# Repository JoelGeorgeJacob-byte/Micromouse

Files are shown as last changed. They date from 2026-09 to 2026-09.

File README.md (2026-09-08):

# Micromouse

An autonomous maze-solving robot designed to navigate a maze by detecting walls, controlling its motion, and executing turns with feedback from multiple sensors.

The robot combines distance sensing, wheel encoders, and an IMU to control its movement and improve its ability to travel straight and execute accurate turns.

## Demo

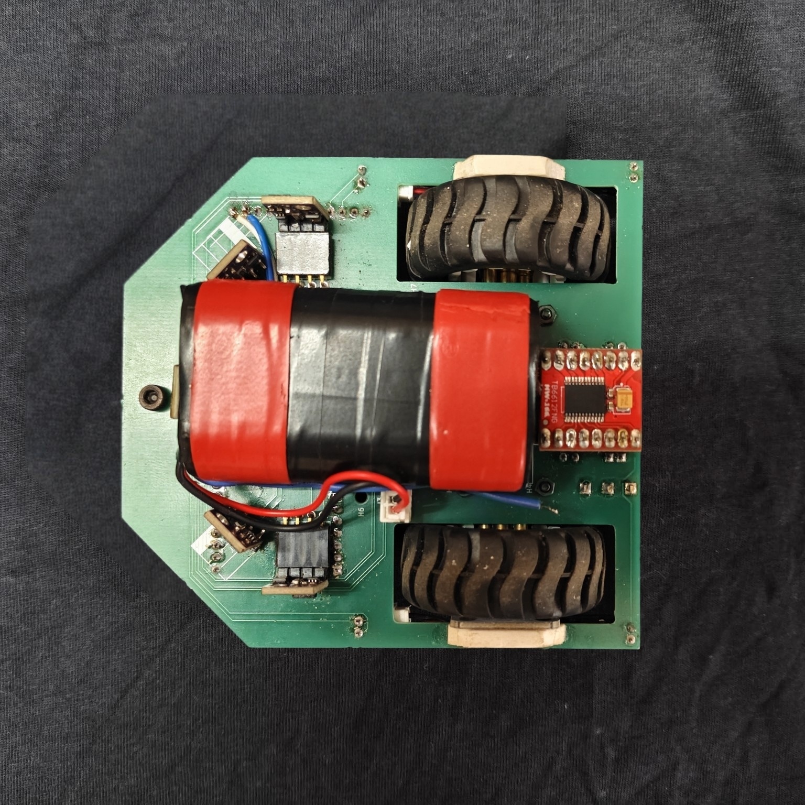
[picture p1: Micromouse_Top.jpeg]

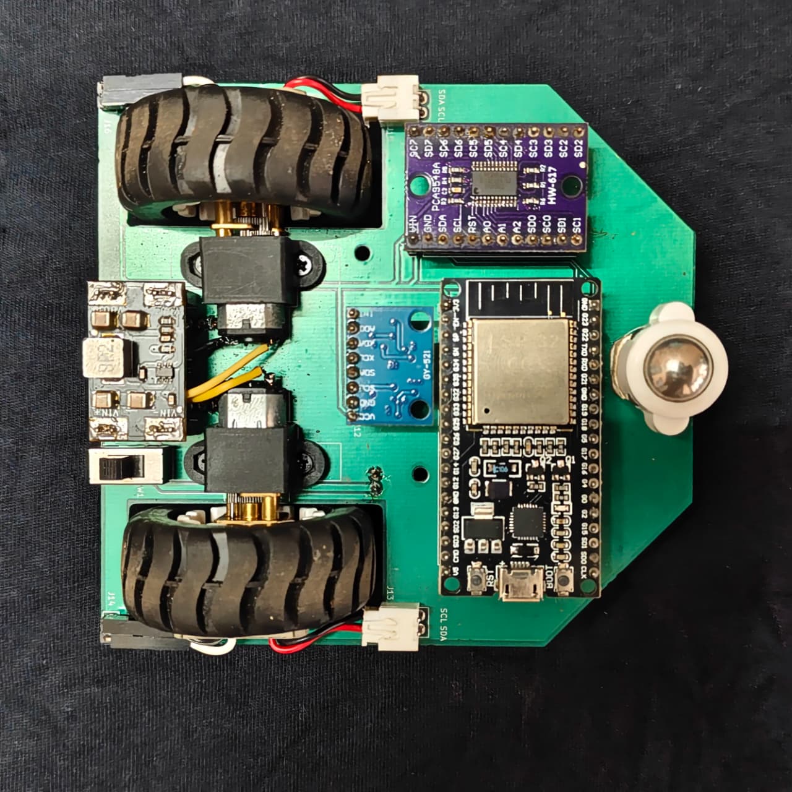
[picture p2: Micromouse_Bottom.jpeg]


## Hardware

* **MCU:** ESP32
* **Motor driver:** TB6612FNG
* **Distance sensing:** 5 × VL53L0X ToF sensors
* **Sensor multiplexer:** TCA9548A
* **Encoders:** 2 × AS5600 magnetic encoders
* **IMU:** MPU6050
* **Motors:** 2 × N20 geared motors
* **Wheels:** 40 mm
* **Power:** 7.4 V Li-ion battery
* **Communication:** I²C

## How It Works

The robot uses multiple VL53L0X ToF sensors to measure the distance to the surrounding walls. The sensors are connected through a TCA9548A I²C multiplexer to allow multiple identical sensors to operate on the same bus.

AS5600 magnetic encoders provide wheel movement feedback, allowing the ESP32 to measure the speed of each motor independently. A closed-loop motor speed controller adjusts the motor PWM to follow the required wheel speeds.

For wall following and centering, the difference between the left and right wall distances is used as the steering error. The controller adjusts the relative speed of the two motors to keep the robot aligned within the corridor.

An MPU6050 gyroscope provides yaw-rate feedback for additional motion stabilization and is also used during turns. Combining encoder feedback, ToF measurements, and gyro feedback allows the robot to control both its translational motion and heading.

The robot's navigation and turning behaviour were developed and tuned through repeated testing on the maze.

## Control System

The robot uses multiple feedback mechanisms:

* **Motor speed control:** Encoder-based closed-loop control
* **Wall centering:** Distance-based steering correction
* **Heading stabilization:** Gyroscope feedback
* **Turn control:** Gyro and encoder-assisted turning
* **Sensor calibration:** Individual sensor and gyro calibration
* **Motor calibration:** Compensation for differences between the two motors

## Challenges & Debugging

### 1. Uncommanded Drift (Hardware Degradation & PID Runaway)

**The Problem:** After a month of inactivity, degradation in the right motor caused the robot to drive straight for 1–2 feet before violently steering into the right wall — with no code changes made in between.

**The Solution:** Traced the fault to the degraded motor rather than the control logic. Replacing the motor and recalibrating resolved the issue, confirming the original PID tuning had been correct all along — the hardware, not the software, had drifted.

### 2. Motor Asymmetry & Open-Loop Calibration

**The Problem:** Out-of-the-box DC motors are never perfectly matched, and after replacing the right motor, the existing PID constants no longer fit the new hardware pairing.

**The Solution:** Wrote a dedicated open-loop calibration script to bypass all navigation logic entirely. By feeding manual PWM values and measuring the response, I calculated exact stiction offsets (`PWM_OFFSET_L/R`) and linear feedforward slopes (`FF_SLOPE_L/R`) for the new motors. This gave the PID controller a mathematically accurate baseline, letting the bot track straight before sensor feedback even engaged.

### 3. Zigzag Blind Spots (Corner Clipping)

**The Problem:** The robot navigated straight corridors cleanly but clipped inner corner pegs during zigzag maneuvers. The original Left/Right/Center ToF layout only looked straight ahead and directly sideways — the 45° front corners of the robot were completely blind.

**The Solution:** Added two diagonal VL53L0X sensors to cover the blind corners. Upgraded the TCA9548A multiplexer's round-robin polling from a 3-state to a 5-state non-blocking switch, so all five sensors could be read continuously without blocking the 100Hz motor control loop.

### 4. Sensor Deadzone Blindness (<40mm Hardware Limit)

**The Problem:** VL53L0X sensors lose accuracy below ~40mm and eventually return a timeout code (8190). Since the steering logic was proportional (`Target − Current Distance`), the correction flatlined or disabled itself right when the robot was inches from a crash.

**The Solution:** Implemented a software "deadzone latch": if a sensor reported a danger-range reading and then suddenly jumped to the 8190 timeout, the system assumed a wall/peg had breached the deadzone and forced the motors into a fixed, aggressive "bang-bang" evasive maneuver instead of trusting the (now-meaningless) proportional value.

### 5. Inertia vs. False Positives (Tuning Hysteresis)

**The Problem:** Setting the evasive trigger distance too short failed outright — at high speeds, the robot's momentum meant it crashed before the wheels could spin down in time. Raising the threshold to a safer distance avoided corner crashes but caused violent swerving on straightaways, since a flat side wall is detected much closer by an angled sensor. Compounding this, raising the danger trigger without properly adjusting the clear trigger broke the hysteresis logic entirely.

**The Solution:** Found the geometric sweet spot just under the straight-wall distance while maintaining a proper hysteresis gap. To compensate for the later trigger point, I added an instant active brake the moment an evasive maneuver starts, giving the tires the grip and time needed to execute a tight pivot instead of skidding into the corner.

### 6. Linear vs. Exponential Correction

**The Problem:** The initial proportional/linear correction produced insufficient response for large positional errors while becoming unnecessarily sensitive around smaller errors. This was particularly noticeable when using the diagonal sensors near angled walls.

**The Solution:** The correction was changed to an exponential response, allowing small deviations to produce gentle corrections while increasing the response more aggressively as the error became larger.

## Results

* **Development Testing:** Successfully and consistently navigated a custom-built test maze during the prototyping phase.
* **Competition Debut:** Competed in Mazerunner Competition conducted by GEC Thrissur, successfully clearing 3 out of 8 corridors on its first official run. 
* **Ongoing Iteration:** The competition highlighted critical edge-cases (such as the zigzag corner-clipping), which directly drove the V2 hardware and software upgrades documented in the challenges above.

The robot was successfully developed from individual hardware components into an autonomous maze-solving platform.

The project involved the development and integration of:

* Sensor-based wall detection
* Encoder-based motor feedback
* Closed-loop motor speed control
* Gyroscope-based heading feedback
* Autonomous turning
* Sensor and motor calibration

The robot was tested and tuned through multiple iterations, with each stage used to identify and correct mechanical, electrical, sensing, and control-related issues.

### Basic Setup

1. Assemble the chassis, motors, sensors, encoders, and motor driver.
2. Connect the VL53L0X sensors and AS5600 encoders through the TCA9548A multiplexer.
3. Connect the MPU6050 to the ESP32.
4. Connect the TB6612FNG to the ESP32 and motors.
5. Upload the firmware to the ESP32.
6. Perform the required sensor and motor calibration.
7. Test straight-line movement and turning before running the robot in the maze.

## Project Structure

* `Micromouse_Code.ino` - Main C++ firmware for the ESP32 (motor control, PID, and navigation).
* `README.md` - Documentation and project overview.
* `Micromouse_Top.jpeg` - Photo of the top view.
* `Micromouse_Bottom.jpeg` - Photo of the bottom view.
* `Micromouse_Gerber.zip` - Raw PCB Gerber file.

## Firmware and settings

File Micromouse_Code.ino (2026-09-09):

#include <Wire.h>
#include <VL53L0X.h>

// ============================================================================
// HARDWARE PIN MAPPING (ESP32 Core 3.x)
// ============================================================================
#define PIN_STBY     19
#define PIN_PWMA     25
#define PIN_AIN1     26
#define PIN_AIN2     27
#define PIN_PWMB     32
#define PIN_BIN1     33
#define PIN_BIN2     23

#define PIN_SDA_MAIN 21
#define PIN_SCL_MAIN 22
#define TCA_ADDR     0x70
#define AS5600_ADDR  0x36

#define PIN_SDA_GYRO 16
#define PIN_SCL_GYRO 17
#define MPU_ADDR     0x68

#define CH_TOF_LEFT   0
#define CH_TOF_DIAG_L 1
#define CH_TOF_CENTER 2
#define CH_TOF_DIAG_R 3
#define CH_TOF_RIGHT  4
#define CH_ENC_LEFT   5
#define CH_ENC_RIGHT  6

// ============================================================================
// CONFIGURATION & TUNING
// ============================================================================
const int SAFE_DIST_MIN     = 45;  
const int SAFE_DIST_MAX     = 80;  
const int FRONT_TURN_DIST   = 100;  

const float BASE_RPM        = 200.0; 
const float MAX_STEER_RPM   = 50.0;  

const float DECEL_ZONE_START_MM = 300.0f; 
const float APPROACH_RPM        = 55.0f;  

const float SAFE_DIST_MID   = (SAFE_DIST_MIN + SAFE_DIST_MAX) / 2.0f;
const float KP_CENTER       = 0.5f;   
const float KD_CENTER       = 0.2f;  

const float KGYRO = 0.30f; 

const int WALL_APPEAR_DIST    = 150;
const int WALL_DISAPPEAR_DIST = 180;

const int   DIAG_DANGER_DIST     = 100;    
const int   DIAG_FLOOR_MM        = 25;   
const int   DIAG_CLEAR_DIST      = 110;   
const int   DIAG_TRIP_DEBOUNCE   = 2;    
const float DIAG_CORRECT_KP      = 3.0f;  
const float DIAG_CORRECT_RPM_MIN = 25.0f; 
const float DIAG_CORRECT_RPM_MAX = 90.0f; 

const float RAMP_STAGE_DIST_MM = 60.0f;                      
const float RAMP_STAGE_RPM[3]  = {60.0f, 80.0f, 100.0f};     
const int   RAMP_STAGE_COUNT   = 3;                          

const float KP_MOTOR = 0.35;
const float KI_MOTOR = 0.80;
const float FF_SLOPE_L = 168.0 / 324.0;
const float FF_SLOPE_R = 149.0 / 302.0;

const int PWM_OFFSET_L = 85;
const int PWM_OFFSET_R = 90;
const float MAX_INTEGRAL_PWM = 40.0;

const int OFFSET_LEFT   = 12;
const int OFFSET_CENTER = 15;
const int OFFSET_RIGHT  = 11;
const int OFFSET_DIAG_L = 16;  
const int OFFSET_DIAG_R = 16;  

const float WHEEL_DIAMETER_MM = 40.0f;
const float MM_PER_COUNT = (PI * WHEEL_DIAMETER_MM) / 4096.0f;

const float GYRO_SENS_LSB_PER_DPS  = 131.0f;  
const float TURN_TARGET_DEG        = 82.0f;
const float HEADING_TOLERANCE_DEG  = 2.0f;    
const float GYRO_RATE_THRESHOLD_DPS= 8.0f;    
const float KP_TURN                = 1.2f;    
const float MIN_PIVOT_RPM          = 45.0f;   
const float MAX_PIVOT_RPM          = 90.0f;
const unsigned long TURN_TIMEOUT_MS = 3000;   

// ============================================================================
// GLOBAL STATE VARIABLES
// ============================================================================
VL53L0X tofLeft, tofCenter, tofRight;
VL53L0X tofDiagL, tofDiagR; 

unsigned long prevMotorTime = 0;
uint8_t tofSequenceState    = 0; 

int16_t prevTickL = -1, prevTickR = -1;
float actualRpmL = 0.0, actualRpmR = 0.0;

float integralL = 0.0, integralR = 0.0;
float smoothSteerRPM = 0.0; 
float smoothForwardRpm = BASE_RPM; 

float targetRpmL = BASE_RPM;
float targetRpmR = BASE_RPM;

int dLeft = 8190, dCenter = 8190, dRight = 8190;
int dDiagL = 8190, dDiagR = 8190; 

bool leftWallPresent  = false;
bool rightWallPresent = false;
bool diagLDanger = false; 
bool diagRDanger = false; 
int diagLTripCount = 0, diagRTripCount = 0; 
unsigned long lastSteerMs = 0;
float prevSteerError = 0.0f;

float distanceSinceTurnMm  = 0.0f;
bool  postTurnRampActive   = false;

float gyroZBiasRaw = 0.0f; 

// ============================================================================
// I2C & HARDWARE UTILITIES
// ============================================================================
void selectMux(uint8_t channel) {
  Wire.beginTransmission(TCA_ADDR);
  Wire.write(1 << channel);
  Wire.endTransmission();
}

int16_t readEncoder(uint8_t channel) {
  selectMux(channel);
  Wire.beginTransmission(AS5600_ADDR);
  Wire.write(0x0C);
  if (Wire.endTransmission(false) != 0) return -1;
  Wire.requestFrom((int)AS5600_ADDR, 2);
  if (Wire.available() < 2) return -1;
  return ((Wire.read() << 8) | Wire.read()) & 0x0FFF;
}

bool tofDataReady(VL53L0X &sensor) {
  return (sensor.readReg(0x13) & 0x07) != 0;
}

// ============================================================================
// GYRO (MPU6050 on Wire1)
// ============================================================================
void mpuWriteReg(uint8_t reg, uint8_t val) {
  Wire1.beginTransmission(MPU_ADDR);
  Wire1.write(reg);
  Wire1.write(val);
  Wire1.endTransmission();
}

int16_t mpuReadGyroZRaw() {
  Wire1.beginTransmission(MPU_ADDR);
  Wire1.write(0x47); 
  if (Wire1.endTransmission(false) != 0) return 0;
  Wire1.requestFrom((int)MPU_ADDR, 2);
  if (Wire1.available() < 2) return 0;
  uint8_t hi = Wire1.read();
  uint8_t lo = Wire1.read();
  return (int16_t)((hi << 8) | lo);
}

void initGyro() {
  Wire1.begin(PIN_SDA_GYRO, PIN_SCL_GYRO);
  Wire1.setClock(400000);

  mpuWriteReg(0x6B, 0x00); 
  delay(50);
  mpuWriteReg(0x1B, 0x00); 

  const int N = 400;
  long sum = 0;
  for (int i = 0; i < N; i++) {
    sum += mpuReadGyroZRaw();
    delay(2);
  }
  gyroZBiasRaw = sum / (float)N;
}

float readGyroZDps() {
  int16_t raw = mpuReadGyroZRaw();
  return (raw - gyroZBiasRaw) / GYRO_SENS_LSB_PER_DPS;
}

// ============================================================================
// LAYER 1: MOTOR SPEED CONTROLLER
// ============================================================================
void initMotors() {
  pinMode(PIN_STBY, OUTPUT);
  pinMode(PIN_AIN1, OUTPUT); pinMode(PIN_AIN2, OUTPUT);
  pinMode(PIN_BIN1, OUTPUT); pinMode(PIN_BIN2, OUTPUT);
  digitalWrite(PIN_STBY, HIGH); 
  
  ledcAttach(PIN_PWMA, 20000, 8);
  ledcAttach(PIN_PWMB, 20000, 8);
}

void applyMotorPWM(int leftPWM, int rightPWM) {
  leftPWM = constrain(leftPWM, -255, 255);
  rightPWM = constrain(rightPWM, -255, 255);

  if (leftPWM >= 0) { digitalWrite(PIN_AIN1, LOW); digitalWrite(PIN_AIN2, HIGH); } 
  else              { digitalWrite(PIN_AIN1, HIGH); digitalWrite(PIN_AIN2, LOW); }
  ledcWrite(PIN_PWMA, abs(leftPWM));

  if (rightPWM >= 0) { digitalWrite(PIN_BIN1, LOW); digitalWrite(PIN_BIN2, HIGH); } 
  else               { digitalWrite(PIN_BIN1, HIGH); digitalWrite(PIN_BIN2, LOW); }
  ledcWrite(PIN_PWMB, abs(rightPWM));
}

void updateEncoders(float dt) {
  int16_t tickL = readEncoder(CH_ENC_LEFT);
  int16_t tickR = readEncoder(CH_ENC_RIGHT);

  float distL = 0.0f, distR = 0.0f;
  bool gotL = false, gotR = false;
  
  if (tickL >= 0 && prevTickL >= 0) {
    int16_t delta = tickL - prevTickL;
    if (delta > 2048) delta -= 4096;
    if (delta < -2048) delta += 4096;
    
    float rawRpmL = (1.0 * delta / 4096.0) * (60.0 / dt);
    actualRpmL = (0.3 * rawRpmL) + (0.7 * actualRpmL); 

    distL = (1.0f * delta) * MM_PER_COUNT; 
    gotL = true;
  }
  
  if (tickR >= 0 && prevTickR >= 0) {
    int16_t delta = tickR - prevTickR;
    if (delta > 2048) delta -= 4096;
    if (delta < -2048) delta += 4096;
    
    float rawRpmR = (-1.0 * delta / 4096.0) * (60.0 / dt);
    actualRpmR = (0.3 * rawRpmR) + (0.7 * actualRpmR); 

    distR = (-1.0f * delta) * MM_PER_COUNT;
    gotR = true;
  }
  
  if (tickL >= 0) prevTickL = tickL;
  if (tickR >= 0) prevTickR = tickR;

  if (postTurnRampActive && gotL && gotR) {
    distanceSinceTurnMm += (distL + distR) / 2.0f;
  }
}

void driveWheelsRPM(float targetL, float targetR, float dt) {
  targetL = constrain(targetL, -220.0, 220.0);
  targetR = constrain(targetR, -220.0, 220.0);

  float errorL = targetL - actualRpmL;
  integralL += errorL * dt;
  integralL = constrain(integralL, -MAX_INTEGRAL_PWM / KI_MOTOR, MAX_INTEGRAL_PWM / KI_MOTOR);

  float ffL = 0;
  if (targetL > 1)       ffL = PWM_OFFSET_L + targetL * FF_SLOPE_L;
  else if (targetL < -1) ffL = -(PWM_OFFSET_L + (-targetL) * FF_SLOPE_L);

  float pwmL = ffL + (KP_MOTOR * errorL) + (KI_MOTOR * integralL);
  pwmL = constrain(pwmL, -255, 255);

  float errorR = targetR - actualRpmR;
  integralR += errorR * dt;
  integralR = constrain(integralR, -MAX_INTEGRAL_PWM / KI_MOTOR, MAX_INTEGRAL_PWM / KI_MOTOR);

  float ffR = 0;
  if (targetR > 1)       ffR = PWM_OFFSET_R + targetR * FF_SLOPE_R;
  else if (targetR < -1) ffR = -(PWM_OFFSET_R + (-targetR) * FF_SLOPE_R);

  float pwmR = ffR + (KP_MOTOR * errorR) + (KI_MOTOR * integralR);
  pwmR = constrain(pwmR, -255, 255);

  applyMotorPWM((int)pwmL, (int)pwmR);
}

// ============================================================================
// LAYER 2 & 3: NAVIGATION & CORNERING
// ============================================================================

float computeRampedForwardRpm() {
  if (!postTurnRampActive) return BASE_RPM;

  int stage = (int)(distanceSinceTurnMm / RAMP_STAGE_DIST_MM);
  if (stage >= RAMP_STAGE_COUNT) {
    postTurnRampActive = false; 
    return BASE_RPM;
  }
  return RAMP_STAGE_RPM[stage];
}

float computeForwardRpm() {
  float target;
  if (dCenter <= 0 || dCenter >= DECEL_ZONE_START_MM) {
    target = BASE_RPM;
  } else if (dCenter <= FRONT_TURN_DIST) {
    target = APPROACH_RPM;
  } else {
    float t = (float)(dCenter - FRONT_TURN_DIST) / (float)(DECEL_ZONE_START_MM - FRONT_TURN_DIST);
    target = APPROACH_RPM + t * (BASE_RPM - APPROACH_RPM);
  }

  float rampTarget = computeRampedForwardRpm();
  if (rampTarget < target) target = rampTarget;

  smoothForwardRpm = 0.3f * target + 0.7f * smoothForwardRpm;
  return smoothForwardRpm;
}

void computeSteering() {
  if (dLeft > 0) {
    if (!leftWallPresent && dLeft < WALL_APPEAR_DIST)       leftWallPresent = true;
    else if (leftWallPresent && dLeft > WALL_DISAPPEAR_DIST) leftWallPresent = false;
  } else {
    leftWallPresent = false;
  }

  if (dRight > 0) {
    if (!rightWallPresent && dRight < WALL_APPEAR_DIST)        rightWallPresent = true;
    else if (rightWallPresent && dRight > WALL_DISAPPEAR_DIST) rightWallPresent = false;
  } else {
    rightWallPresent = false;
  }

  float effLeft  = leftWallPresent  ? (float)dLeft  : SAFE_DIST_MID;
  float effRight = rightWallPresent ? (float)dRight : SAFE_DIST_MID;
  float error = effRight - effLeft;

  unsigned long nowMs = millis();
  float dt = (lastSteerMs == 0) ? 0.02f : (nowMs - lastSteerMs) / 1000.0f;
  if (dt <= 0.0f) dt = 0.001f;
  lastSteerMs = nowMs;

  float derivative = (error - prevSteerError) / dt;
  prevSteerError = error;

  float yawRateDps = readGyroZDps();

  float rawSteerRPM = KP_CENTER * error + KD_CENTER * derivative - KGYRO * yawRateDps;
  rawSteerRPM = constrain(rawSteerRPM, -MAX_STEER_RPM, MAX_STEER_RPM);

  smoothSteerRPM = (0.3 * rawSteerRPM) + (0.7 * smoothSteerRPM);

  float baseRpm = computeForwardRpm();
  targetRpmL = baseRpm + smoothSteerRPM;
  targetRpmR = baseRpm - smoothSteerRPM;

  if (dDiagL > 0 && dDiagL < DIAG_DANGER_DIST) {
    diagLTripCount++;
    if (!diagLDanger && diagLTripCount >= DIAG_TRIP_DEBOUNCE) diagLDanger = true;
  } else {
    diagLTripCount = 0;
    if (diagLDanger && (dDiagL <= 0 || dDiagL > DIAG_CLEAR_DIST)) diagLDanger = false;
  }

  if (dDiagR > 0 && dDiagR < DIAG_DANGER_DIST) {
    diagRTripCount++;
    if (!diagRDanger && diagRTripCount >= DIAG_TRIP_DEBOUNCE) diagRDanger = true;
  } else {
    diagRTripCount = 0;
    if (diagRDanger && (dDiagR <= 0 || dDiagR > DIAG_CLEAR_DIST)) diagRDanger = false;
  }

  if (diagLDanger) {
    float correctRpm;
    if (dDiagL <= DIAG_FLOOR_MM) {
      correctRpm = DIAG_CORRECT_RPM_MAX; 
    } else {
      float penetration = (float)DIAG_DANGER_DIST - (float)dDiagL;
      float linear_rpm = DIAG_CORRECT_RPM_MIN + DIAG_CORRECT_KP * penetration;
      
      float safe_dist = max((float)dDiagL, 1.0f); 
      float proximity_ratio = (float)DIAG_DANGER_DIST / safe_dist;
      float multiplier = proximity_ratio * proximity_ratio;
      
      correctRpm = linear_rpm * multiplier;
      correctRpm = constrain(correctRpm, DIAG_CORRECT_RPM_MIN, DIAG_CORRECT_RPM_MAX);
    }
    targetRpmL = baseRpm + correctRpm; 
    targetRpmR = baseRpm - correctRpm; 
    
  } else if (diagRDanger) {
    float correctRpm;
    if (dDiagR <= DIAG_FLOOR_MM) {
      correctRpm = DIAG_CORRECT_RPM_MAX;
    } else {
      float penetration = (float)DIAG_DANGER_DIST - (float)dDiagR;
      float linear_rpm = DIAG_CORRECT_RPM_MIN + DIAG_CORRECT_KP * penetration;
      
      float safe_dist = max((float)dDiagR, 1.0f);
      float proximity_ratio = (float)DIAG_DANGER_DIST / safe_dist;
      float multiplier = proximity_ratio * proximity_ratio;
      
      correctRpm = linear_rpm * multiplier;
      correctRpm = constrain(correctRpm, DIAG_CORRECT_RPM_MIN, DIAG_CORRECT_RPM_MAX);
    }
    targetRpmL = baseRpm - correctRpm; 
    targetRpmR = baseRpm + correctRpm; 
  }
}

void executePivotTurn() {
  digitalWrite(PIN_AIN1, HIGH); digitalWrite(PIN_AIN2, HIGH);
  digitalWrite(PIN_BIN1, HIGH); digitalWrite(PIN_BIN2, HIGH);
  ledcWrite(PIN_PWMA, 255); ledcWrite(PIN_PWMB, 255);
  delay(60);
  applyMotorPWM(0, 0);
  delay(100); 

  integralL = 0;
  integralR = 0;
  smoothSteerRPM = 0;

  bool turnLeft = (dLeft > dRight);
  float currentHeadingDeg = 0.0f;
  float targetHeadingDeg = 999.0f; 
  bool centerCleared = false;

  float scanRpm = 45.0f; 

  unsigned long turnStartMs  = millis();
  unsigned long lastMotorMs  = millis();
  unsigned long lastGyroUs   = micros();

  while (true) {
    unsigned long nowMs = millis();
    unsigned long nowUs = micros();

    float gz = readGyroZDps();
    float gdt = (nowUs - lastGyroUs) / 1e6f;
    if (gdt > 0.0f) {
      currentHeadingDeg += gz * gdt;
      lastGyroUs = nowUs;
    }

    selectMux(CH_TOF_CENTER);
    if (tofDataReady(tofCenter)) {
      int raw = tofCenter.readRangeContinuousMillimeters();
      dCenter = (tofCenter.timeoutOccurred() || raw > 8000) ? 8190 : raw - OFFSET_CENTER;
    }

    float pivotRpm = 0.0f;

    if (!centerCleared) {
      if (dCenter > 160 && fabs(currentHeadingDeg) > 40.0f) { 
        centerCleared = true;
        
        targetHeadingDeg = currentHeadingDeg + (turnLeft ? 32.0f : -32.0f);
        
        Serial.printf("Opening found at %.1f deg. Squaring up to %.1f deg.\n", currentHeadingDeg, targetHeadingDeg);
      }
      
      pivotRpm = turnLeft ? scanRpm : -scanRpm; 
      
    } else {
      float headingError = targetHeadingDeg - currentHeadingDeg;
      pivotRpm = KP_TURN * headingError;
      pivotRpm = constrain(pivotRpm, -MAX_PIVOT_RPM, MAX_PIVOT_RPM);
      
      if (fabs(headingError) > HEADING_TOLERANCE_DEG && fabs(pivotRpm) < MIN_PIVOT_RPM) {
        pivotRpm = (pivotRpm >= 0) ? MIN_PIVOT_RPM : -MIN_PIVOT_RPM;
      }

      if (fabs(headingError) < HEADING_TOLERANCE_DEG && fabs(gz) < GYRO_RATE_THRESHOLD_DPS) {
        break; 
      }
    }

    if (nowMs - lastMotorMs >= 10) {
      float dt = (nowMs - lastMotorMs) / 1000.0f;
      lastMotorMs = nowMs;
      updateEncoders(dt);
      
      if (!centerCleared) {
          float leftSpeed = turnLeft ? -scanRpm : scanRpm;
          float rightSpeed = turnLeft ? scanRpm : -scanRpm;
          driveWheelsRPM(leftSpeed, rightSpeed, dt);
      } else {
          driveWheelsRPM(-pivotRpm, pivotRpm, dt);
      }
    }

    if (nowMs - turnStartMs > TURN_TIMEOUT_MS) break;
  }

  digitalWrite(PIN_AIN1, HIGH); digitalWrite(PIN_AIN2, HIGH);
  digitalWrite(PIN_BIN1, HIGH); digitalWrite(PIN_BIN2, HIGH);
  ledcWrite(PIN_PWMA, 255); ledcWrite(PIN_PWMB, 255);
  delay(60);
  applyMotorPWM(0, 0);
  delay(100);

  integralL = 0;
  integralR = 0;

  selectMux(CH_TOF_LEFT);
  int rL = tofLeft.readRangeContinuousMillimeters();
  dLeft = (tofLeft.timeoutOccurred() || rL > 8000) ? 8190 : rL - OFFSET_LEFT;

  selectMux(CH_TOF_CENTER);
  int rC = tofCenter.readRangeContinuousMillimeters();
  dCenter = (tofCenter.timeoutOccurred() || rC > 8000) ? 8190 : rC - OFFSET_CENTER;

  selectMux(CH_TOF_RIGHT);
  int rR = tofRight.readRangeContinuousMillimeters();
  dRight = (tofRight.timeoutOccurred() || rR > 8000) ? 8190 : rR - OFFSET_RIGHT;

  selectMux(CH_TOF_DIAG_L); 
  int rDL = tofDiagL.readRangeContinuousMillimeters();
  dDiagL = (tofDiagL.timeoutOccurred() || rDL > 8000) ? 8190 : rDL - OFFSET_DIAG_L;

  selectMux(CH_TOF_DIAG_R); 
  int rDR = tofDiagR.readRangeContinuousMillimeters();
  dDiagR = (tofDiagR.timeoutOccurred() || rDR > 8000) ? 8190 : rDR - OFFSET_DIAG_R;

  leftWallPresent  = (dLeft  > 0 && dLeft  < WALL_APPEAR_DIST);
  rightWallPresent = (dRight > 0 && dRight < WALL_APPEAR_DIST);
  diagLDanger = (dDiagL > 0 && dDiagL < DIAG_DANGER_DIST); 
  diagRDanger = (dDiagR > 0 && dDiagR < DIAG_DANGER_DIST); 
  diagLTripCount = 0; 
  diagRTripCount = 0; 
  prevSteerError = 0.0f;
  lastSteerMs = 0; 

  distanceSinceTurnMm = 0.0f;
  postTurnRampActive  = true; 
}

// ============================================================================
// SYSTEM BOOTSTRAP
// ============================================================================
void setup() {
  Serial.begin(115200);
  Wire.begin(PIN_SDA_MAIN, PIN_SCL_MAIN);
  Wire.setClock(400000); 

  initMotors();
  applyMotorPWM(0, 0);

  bool leftOk, centerOk, rightOk, diagLOk, diagROk;

  selectMux(CH_TOF_LEFT);
  leftOk = tofLeft.init();
  tofLeft.setTimeout(50);
  tofLeft.setMeasurementTimingBudget(20000);
  tofLeft.startContinuous(); 

  selectMux(CH_TOF_CENTER);
  centerOk = tofCenter.init();
  tofCenter.setTimeout(50);
  tofCenter.setMeasurementTimingBudget(20000);
  tofCenter.startContinuous();

  selectMux(CH_TOF_RIGHT);
  rightOk = tofRight.init();
  tofRight.setTimeout(50);
  tofRight.setMeasurementTimingBudget(20000);
  tofRight.startContinuous();

  selectMux(CH_TOF_DIAG_L);
  diagLOk = tofDiagL.init();
  tofDiagL.setTimeout(50);
  tofDiagL.setMeasurementTimingBudget(20000);
  tofDiagL.startContinuous();

  selectMux(CH_TOF_DIAG_R);
  diagROk = tofDiagR.init();
  tofDiagR.setTimeout(50);
  tofDiagR.setMeasurementTimingBudget(20000);
  tofDiagR.startContinuous();

  Serial.printf("ToF init -> Left:%s  Center:%s  Right:%s  DiagL:%s  DiagR:%s\n",
                leftOk ? "OK" : "FAILED",
                centerOk ? "OK" : "FAILED",
                rightOk ? "OK" : "FAILED",
                diagLOk ? "OK" : "FAILED",
                diagROk ? "OK" : "FAILED");
  if (!centerOk) {
    Serial.println("WARNING: front/center ToF failed to init - turns will never trigger.");
  }
  if (!diagLOk || !diagROk) {
    Serial.println("WARNING: a diagonal ToF failed to init - corner-clip override on that side is disabled.");
  }

  initGyro();

  delay(2000); 
  prevMotorTime = millis();
}

// ============================================================================
// MAIN LOOP: SCHEDULER
// ============================================================================
void loop() {
  unsigned long now = millis();

  if (now - prevMotorTime >= 10) {
    float dt = (now - prevMotorTime) / 1000.0;
    prevMotorTime = now;

    updateEncoders(dt);
    driveWheelsRPM(targetRpmL, targetRpmR, dt);
  }

  switch (tofSequenceState) {
    case 0: 
      selectMux(CH_TOF_LEFT);
      if (tofDataReady(tofLeft)) {
        int raw = tofLeft.readRangeContinuousMillimeters();
        dLeft = (tofLeft.timeoutOccurred() || raw > 8000) ? 8190 : raw - OFFSET_LEFT;
      }
      tofSequenceState = 1;
      break;
      
    case 1: 
      selectMux(CH_TOF_CENTER);
      if (tofDataReady(tofCenter)) {
        int raw = tofCenter.readRangeContinuousMillimeters();
        dCenter = (tofCenter.timeoutOccurred() || raw > 8000) ? 8190 : raw - OFFSET_CENTER;
      }
      tofSequenceState = 2;
      break;
      
    case 2: 
      selectMux(CH_TOF_RIGHT);
      if (tofDataReady(tofRight)) {
        int raw = tofRight.readRangeContinuousMillimeters();
        dRight = (tofRight.timeoutOccurred() || raw > 8000) ? 8190 : raw - OFFSET_RIGHT;
      }
      tofSequenceState = 3;
      break;

    case 3: 
      selectMux(CH_TOF_DIAG_L);
      if (tofDataReady(tofDiagL)) {
        int raw = tofDiagL.readRangeContinuousMillimeters();
        dDiagL = (tofDiagL.timeoutOccurred() || raw > 8000) ? 8190 : raw - OFFSET_DIAG_L;
      }
      tofSequenceState = 4;
      break;

    case 4: 
      selectMux(CH_TOF_DIAG_R);
      if (tofDataReady(tofDiagR)) {
        int raw = tofDiagR.readRangeContinuousMillimeters();
        dDiagR = (tofDiagR.timeoutOccurred() || raw > 8000) ? 8190 : raw - OFFSET_DIAG_R;
      }
      tofSequenceState = 0;
      break;
  }

  static unsigned long lastSteerUpdateMs = 0;
  const unsigned long STEER_UPDATE_PERIOD_MS = 20;
  if (now - lastSteerUpdateMs >= STEER_UPDATE_PERIOD_MS) {
    lastSteerUpdateMs = now;

    if (dCenter > 0 && dCenter < FRONT_TURN_DIST) {
      Serial.printf(">> TURN TRIGGERED  L:%d  C:%d  R:%d\n", dLeft, dCenter, dRight);
      executePivotTurn();
    } else {
      computeSteering();
    }
  }

  static unsigned long lastDebugMs = 0;
  if (now - lastDebugMs >= 200) {
    lastDebugMs = now;
    Serial.printf("L:%d  DL:%d  C:%d  DR:%d  R:%d  steer:%.1f  fwd:%.1f\n",
                  dLeft, dDiagL, dCenter, dDiagR, dRight, smoothSteerRPM, smoothForwardRpm);
  }
}
    Serial.printf("L:%d  DL:%d  C:%d  DR:%d  R:%d  steer:%.1f  fwd:%.1f\n",
                  dLeft, dDiagL, dCenter, dDiagR, dRight, smoothSteerRPM, smoothForwardRpm);
  }
}
